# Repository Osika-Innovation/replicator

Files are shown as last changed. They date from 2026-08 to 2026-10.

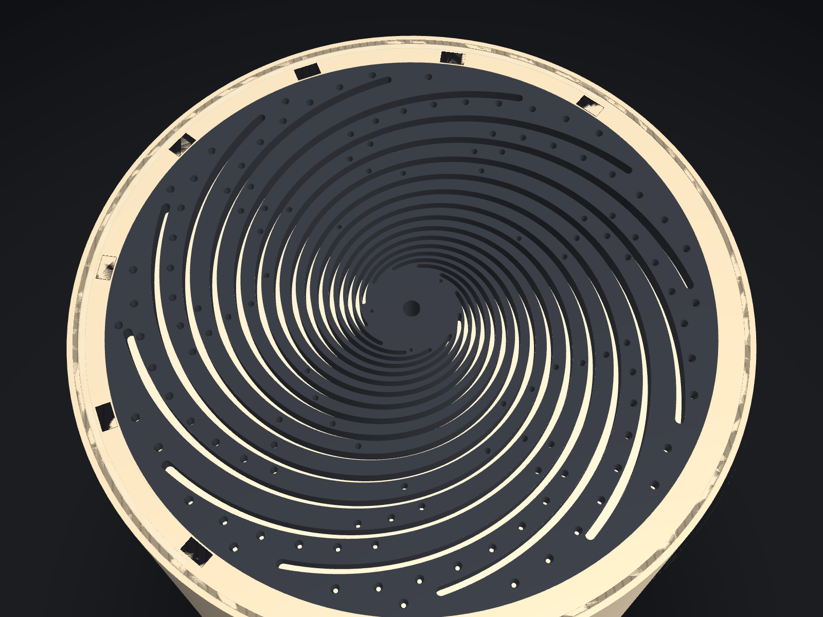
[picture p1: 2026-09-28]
cad/rh1-freestanding/renders/rh1_plate.png

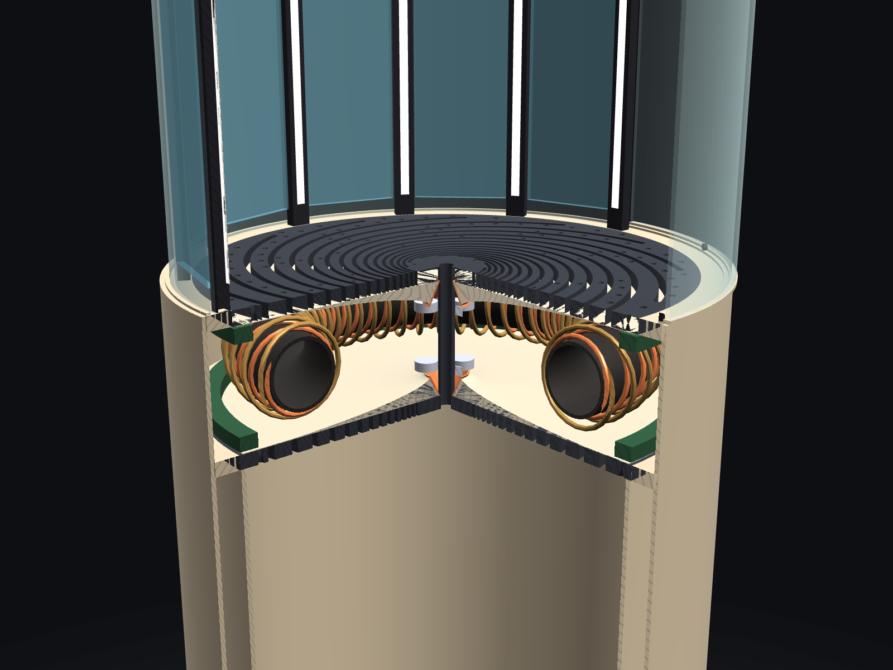
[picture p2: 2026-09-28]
cad/rh1-freestanding/renders/rh1_detail.png

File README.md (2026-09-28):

# The Replicator

**Holographic matter manipulation** — a machine that scans, assembles, and
dissolves objects with shaped acoustic and electromagnetic fields. No nozzle,
no moving parts: the walls of the build chamber command the field, the field
commands the matter.

This is the open engineering repository of
[Osika Innovation](https://osika-innovation.lovable.app). The guided story —
architecture, physics, roadmap — lives on the site; this repo is the working
material behind it: the digital twin, the CAD, and the research papers.

> Two chambers — one holds the object, one holds the matter it will become;
> between them, one plate.

## Layout

| Path | What it is |
|---|---|
| [`twin/`](twin/) | **RSW-1, the field compiler** — the machine's digital twin. Native Swift + Metal: the free-standing RH-1 as a parametric solid model ([`twin/CAD.md`](twin/CAD.md) — 92 parts, CAD gates, section-cut Machine tab, STL/OBJ/STEP export), T0 Rayleigh–Sommerfeld propagator with exact adjoint, T1 acoustic FDTD, T2 Gor'kov radiation forces, inverse solvers (IBP / GS-PAT / Diff-PAT), physics acceptance gates that write receipts, and a headless render/screenshot harness. `swift build` and go — no Xcode required. |
| [`papers/`](papers/) | The research corpus: principles, architecture, the RH-1 hardware specification, the three modes (scan / assemble / dissolve), the two carriers (phonons / photons), stores, memory & compute, bounds analysis, and the field-compiler specification. |
| [`cad/`](cad/) | [`cad/rh1-freestanding/`](cad/rh1-freestanding/) — the RH-1 CAD **generated by the twin**: STEP assembly, general-arrangement drawing, BOM, parameters, renders, and a rev3 Blender render model; plus plate and table-assembly sources (OpenSCAD / CadQuery) and the 12-port bench chamber. `rh1_freestanding_rev2.blend` is kept for history and is superseded (it predates the Ø12 bore). |
| [`sims/`](sims/) | Pre-registered simulation studies. Predictions are frozen before the run and results are published either way — including the negative ones (see the quasicrystal array study in `papers/`). |

## How we work

Every claim in the papers carries a register — **measured** (demonstrated in
published experiments), **derived** (follows from measured physics by
calculation), or **open** (not yet demonstrated, named as such, attached to a
concrete gate). Candidate designs are tested against pre-registered criteria,
and design decisions are recorded with their full history; nothing is
silently rewritten. The twin enforces the same discipline in code: physics
acceptance gates write timestamped receipts, and the emulator's API is the
hardware's API.

## Licensing

- Code (`twin/`, `sims/`) — [Apache License 2.0](LICENSE)
- Hardware design files (`cad/`) — [CERN-OHL-P v2](cad/LICENSE)
- Papers (`papers/`) — © Osika Innovation, all rights reserved for now;
  published openly on the [site](https://osika-innovation.lovable.app/research)

We publish our designs because we would rather live in a world where a
hundred groups extend this machine than one where one company owns it.

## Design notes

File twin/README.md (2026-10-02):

# field-compiler — RSW-1

Native macOS implementation of the Field Compiler.
Spec: [`papers/replicator_field_compiler.html`](../papers/replicator_field_compiler.html) (v0.8).
CAD: [`CAD.md`](CAD.md) — the free-standing RH-1 as a parametric solid model inside the twin.

## Build and run

No Xcode required — Command Line Tools only.

```sh
swift build -c release
./.build/release/fieldc test              # unit suite (62 tests; FIELDC_VERBOSE=1 prints every measured value)
./.build/release/fieldc gate --receipt    # physics acceptance gates, writes Receipts/
./.build/release/fieldc machine           # the simulated machine: RH-1 free-standing, room air (--desktop: frozen v0.3)
./.build/release/fieldc focus             # compile a centre trap on the full chamber (GPU port fields)
./.build/release/fieldc gpu               # Metal propagator + port-field kernel vs CPU reference
./.build/release/fieldc drift --receipt   # how fast a compiled trap goes stale as the air warms
./.build/release/fieldc forcetrap --receipt   # compile for force vs GS-PAT: unique trap? thermal hold? (--glass)
./.build/release/fieldc tonesweep --receipt   # glass chamber: sibling ratio vs number of tones (--target, --liner)
./.build/release/fieldc wallsweep --receipt   # glass liner / plate reflection grid (--plates)
./.build/release/fieldc levitate --receipt    # the drive to hold PLA / aluminium / steel against gravity, in SI
./.build/release/fieldc carry --receipt       # pick up, carry 5 mm up and 5 mm across, place (G-P1)
./.build/release/fieldc fly --receipt         # integrate a PLA bead through the carry: drive level × step time (G-P2)
./.build/release/fieldc build --receipt       # the first build: N beads laid in a row on a support (G-B1; --beads N)
./.build/release/fieldc build --shape tetra --row-dir y --receipt   # four beads: a triangle and one in its pocket (G-B2)
./.build/release/fieldc arraysweep --receipt  # open air: what N elements per plate and the tones buy (study S1)
./.build/release/fieldc mold --receipt        # the sieve in open air, 2 × 192 elements (--shape tetra, --rotate, --sites, --light)
./.build/release/fieldc mold --chamber glass --receipt   # the glass chamber of Rounds 7–11 (--objective wells: the λ/4 limit)
./.build/release/fieldc scan3d --object ring --receipt   # gated pulse-echo scan in open air (point | ring | tetra | R; --chamber glass)
./.build/release/fieldc replicate --receipt   # scan → read the shape → mold a copy → scan the copy (--object tetra)
./.build/release/fieldc render iso a.png  # offscreen machine render, no window server
./.build/release/fieldc shot --all        # every UI scene, both themes + contact sheet
./.build/release/fieldc broadband         # channel-count study: free field vs cavity+chord
./.build/release/fieldc cad check --rules  # the RH-1 solid model: CAD gates + design rules
./.build/release/fieldc cad render --all   # iso, front, section, detail, plate, storage, top
./.build/release/fieldc cad export         # STL per part, OBJ+MTL, params, BOM, GA drawing
./.build/release/fieldc cad step           # B-rep STEP assembly via CadQuery, volume-gated
./.build/release/fieldc plates             # can 6 throat gates hold a trap? (model study)
```

## Status — honest

**2026-09-28 — the machine exists as CAD, and the physics reads it.** The
twin now carries the free-standing RH-1 (Ø460 × 1650, three plate assemblies,
four radiating faces, two chambers, rotating glass, arcade, six photonic bays)
as a parametric solid model built from the newest sources — etherworks.io
(2026-08-10), mech §3c (2026-08-03), spec v0.4 — with every number's
provenance and nine documented conflicts resolved in code (see
[`CAD.md`](CAD.md)). 92 closed solids, 9 CAD gates + 25 design rules, a shaded
section-cut Machine tab, STL/OBJ/STEP exports with a cross-kernel volume gate.
A new preset, `RH1Freestanding`, takes its acoustic apertures from the CAD's
plate faces and its gates from the throat piezos; the desktop preset (`RH1`,
24 panel gates) is FROZEN: it backs the historical solver gates below and
replays old receipts, nothing else.

**2026-09-29 — every mode now simulates the free-standing machine, in real
air.** Compile/Build/Inspect, the viewport chrome, `focus` and `render` run on
`RH1Freestanding.standard()`: 6 throat gates, 17 184 virtual apertures, both
plates as walls, humid air at 20 °C / 50 % RH. See "Round 6" below.

**2026-09-29, later — the glass chamber, exactly, and unique traps inside it.**
The build chamber is modelled as the glass cylinder it is (bare or lined), and
a force compiler that works in its speckle holds one trap with 3–10 tones, on
axis and off. A liner is not the lever; temperature tracking is. See "Round 7".

**2026-09-29, evening — how hard to drive, and a carried bead.** In SI units a
PLA bead needs ~160 dB and steel ~168 dB in the glass chamber (MODEL: the horn
is a stub). The twin carries a trap 5 mm up and 5 mm across on its point,
downhill every step (G-P1). A PLA bead integrated through the fields rides it
at 4× the holding drive, 10 mm in 0.4 s (G-P2). See "Round 8".

**2026-09-30 — the first builds.** Five PLA beads are laid in a row on a
support, each within 2–3.5 µm of its site and touching its neighbour (7–9 µm
gaps). This works by compiling the force balance rather than the potential
minimum, and by placing closed-loop (G-B1). A tetrahedron follows: a fourth
bead rests on three, touching all of them (G-B2). See "Round 9".

**2026-09-30, night — scan an object, mold from powder.** The twin images a
3D object from the six gates (a 30 mm tetrahedron frame at 100 % recall; the
letter R readable). A random cloud of Ø40 µm powder then ends 100 % on a
16-site ring, and 100 % on a 12 mm tetrahedron frame, within 2–4 s. That works
as a sieve: gravity carries the powder, and the compiled field makes the shape
the only place that can hold a grain up. A mold of wells alone catches only
the ~23 % that starts within λ/4 of the shape. Open: an even share per site.
See "Round 11".

**2026-10-01 — the axis bug.** The GPU cavity fields were exactly zero on the
chamber axis, where every mid-plane target sits. Fixed and gated
(G-GPU-CYL-axis); every affected receipt was re-run at 77df809, and the
conclusions of Rounds 7–11 hold with corrected numbers. See "Round 11".

**2026-10-01, later — open air, and the loop closes.** Per
[`ENGINE.md`](ENGINE.md) the glass is gone: two Ø410 mm plates in open air,
each a surface of N independently driven elements. The engine is
matrix-free on the GPU (a mold compile takes minutes of GPU and seconds of
CPU) with basin maps instead of particle stepping. Channels buy power; tones
buy confinement (2 × 192 elements, 9 tones over 30–70 kHz). The scan is
time-gated pulse-echo. The replicator's loop — scan a wire ring, read it,
mold it from powder, scan the copy — closes with every gate passing. Open:
reading small 3D wireframes; evenness that does not depend on orientation.
See "Round 12".

**Implemented and gated:** FieldCore (pure Swift, zero dependencies) —
complex/vector math, RH-1 geometry, mesh + voxelizer, T0 Rayleigh–Sommerfeld
propagator with exact adjoint, T1 acoustic FDTD, T2 Gor'kov radiation force,
the inverse solver (IBP / GS-PAT / Diff-PAT), gate framework and receipts.

**FieldGPU (Metal):** runtime-compiled shaders, GPU propagator validated against
the CPU reference to 3.8e-6, scene geometry for the RH-1 machine, an orbit camera,
and offscreen rendering to CGImage — the viewport half of the screenshot harness,
working with no window server.

**FieldUI (SwiftUI):** the slicer shell — mode tabs, object rail, viewport pane
with overlay chips, inspector, transport bar — as a pure function of `AppState`
(law L1). Dark and light themes. An 8-scene registry and a contact-sheet
generator; `fieldc shot --all` produces 16 PNGs plus two contact sheets headlessly.

**Machine model now carries the two levers a plain-array model lacks:** cavity
walls (axial image sources) and per-tone rainbow gate→element weights.

**Scan pipeline (M7) — wired end to end, physics PARTLY validated.**
`fieldc scan` runs: FDTD pulse-echo with a scatterer → empty-chamber reference →
differential → real S[rx][tx] scattering matrix → matrix pencil → chords →
`.pattern` → Machine View L0 → gates. Working and gated: `.pattern` round trip
bit-exact (G11), reciprocity QC on a genuine scattering matrix (G15, 0.001), and
**L1 DORT correctly REFUSES to image without a measured Green's function** — the
guard that stops a confident, sharp, meaningless picture reaching a `.pattern`.
Chord extraction recovers a pole at **10.68 kHz against a 10.72 kHz drive**,
which says the pencil is finding real physics.

**Not yet built / not yet working:** T0.5 BEM, T1f CBS, T3 consolidation,
`.fcode` I/O, Machine View L2–L3, golden-image *diffing* (screenshots generate
but are not compared against committed goldens), live MTKView interaction.

So: **M0–M2 and M4 done and gated; M1 done for geometry and viewport; M7 wired
with two known defects (below); M3, M5, M6, M8, M9 not.**

## Gate results (Apple M5)

All 10 gates pass. `G9b` reports informational — see below.

| gate | measures | result |
|---|---|---|
| G1 | voxelizer volume vs 4/3πr³ | 0.40% (bar 2%) |
| G2 | energy drift, lossless, 10k steps | 0.71% (bar 1%) |
| G3 | axial round-trip time of flight | 0.44% (bar 2%) |
| G6 | standing-wave node spacing vs λ/2 | 2.5e-5 (bar 1%) |
| G7 | Gor'kov numeric vs closed form | 3.6e-7 (bar 2%) |
| G9a | lateral focus placement, single plate | 1.79 mm (bar 2.64 mm) |
| G9c | best method vs IBP focusing gain | 1.00× (bar > 0.98) |

## Round 12 — open air, physics-limited plates, an engine built on linearity (2026-10-01)

Built to [`ENGINE.md`](ENGINE.md), after the operator's decisions of 1 October:

* keep the cylinder but drop the glass (two Ø410 mm plates, 460 mm apart,
  open air between them);
* make each plate a holographic surface limited by physics, not by "three
  horns per face";
* make the engine efficient before spending compute on it.

### The engine

* **Plates of independently driven elements** (`PlateArray`). Each plate
  carries N Ø5 mm pistons on a Vogel spiral, so every element sits at its
  own radius and there are no grating lobes. Each element has its own drive
  channel. The plates reflect with R = 0.9, imaged to order 3.
* **Matrix-free on the GPU** (`ArrayFieldGPU`, `Shaders/array.metal`).
  * One pass gives p and ∇p at any points for a drive.
  * A second gives, for every element, the gradient of any weighted sum of
    the Gor'kov potential.
  * Nothing is stored, so N can be thousands.

  Gates: G-A1 (potential vs the CPU reference) 3.4e-5; G-A3 (adjoint)
  5.6e-5; G-A2 (one element vs the Rayleigh integral over its face, at
  230 mm and 0–42°) 0.87 %.
* **One compiler for any field** (`ForceCompiler.ForceField`). The mold,
  funnel and sieve compilers run on the glass chamber's stored rows or on
  the plate array.
* **Basin maps instead of trajectories** (`BasinMap`). Overdamped powder
  slides down U_eff = P·U + mgz and stops in a minimum. So every lattice cell
  points to its steepest descent, and following the pointers gives the end
  of every start at once. Recirculation closes in one line. G-B0: the basin
  map and 3,000 stepped grains agree on the share that ends on the shape.
* **Basin-map feedback.** Sites that get less than their fair share are
  weighted up and the drive is recompiled from the last one. This is what
  the machine would do with a scan.
* **Cost.** A mold compile at the design point takes 2–3 minutes of GPU
  time with a few seconds of CPU; a scan takes ~45 s; peak memory is
  ~50 MB.
  * Per-call GPU buffers were first kept alive by their command buffers and
    grew 0.4 GB/s. That killed the first sweep silently. Buffers are now
    allocated once per field.

### What the channel count and the tones buy (`fieldc arraysweep`, study S1; receipt at 9e5b63d)

Centre-trap ratio (< 0.5 = unique), and the 16-site ring sieve by the basin map:

| per plate | tones (30–70 kHz) | trap ratio | powder on the ring | sites (fair 6.25 %) | drive per element | acoustic power |
|---|---|---|---|---|---|---|
| 3 | 1 | 0.78 | 4 % | — | 476 m/s | 5,512 W |
| 12 | 3 | 0.18 | 97 % | 0–25 % | 51 m/s | 745 W |
| 48 | 9 | 0.10 | 100 % | 0–16.5 % | 10 m/s | 349 W |
| 192 | 1 | 0.67 | 15 % | — | 9.2 m/s | 131 W |
| 192 | 9 | 0.11 | 100 % | 3.3–8.6 % | 2.2 m/s | 67 W |
| 768 | 9 | 0.08 | 100 % | 4.0–9.3 % | 0.62 m/s | 21 W |

What the channel count and the tones buy

* **Tones buy confinement along the axis.** Two plates make standing waves
  every λ/2 all the way between them, so lift exists at every node plane.
  Only frequency diversity localises it. One tone never makes a unique trap
  (~0.7 at any N). Nine tones over 30–70 kHz make the centre trap unique
  (~0.1), and the sieve puts all the powder on the ring. This is Round 7's
  "tones are drives", now separated from the channel count.
* **Channels buy power and evenness.** Going from 3 to 768 elements per
  plate cuts the acoustic power ~100–170×. Every site getting its share needs
  192 or more.
* **Design point:** 2 × 192 elements, 9 tones over 30–70 kHz. That is
  ~2.2 m/s rms per element and ~67 W acoustic to hold the whole powder
  cloud. At 2 × 768 it drops to 0.6 m/s and 21 W.

### Molds in open air (receipts at 9af9c1f)

At the design point (2 × 192 elements, 9 tones), with the basin map and
3,000 stepped grains:

* **The 16-site ring:** 100 % of the powder ends on the ring. All 16 sites
  hold powder (3.3–8.6 % each against a fair 6.25 %; grains 21–348 each).
  Nothing is left in a rogue well; 1.2 re-sprinkles per grain (G-M1, G-M2,
  G-B0 pass).

  Open air: the ring
* **The 12 mm tetrahedron frame, in 3D:** 98.5 % on the frame by the basin
  map, 100 % by the grains. All 10 sites hold powder (7.7–13.1 % against a
  fair 10 %) (G-M1, G-M2, G-B0 pass).

  Open air: the tetrahedron frame
* **Evenness depends on orientation (found by turning the shape).**
  * Capture onto the shape is robust: 100 % at every rotation tried.
  * Even filling is not. The 16-site ring (sites 3.1 mm apart) leaves sites
    empty when turned 5° or 11.25°.
  * With 12 sites (4.2 mm apart) every site fills at 0° and 5° (7.4–9.1 %,
    6.4–10.3 %) but one stays empty at 11.25°.

  The plates' Vogel spirals are not rotationally symmetric, and 3.1 mm is
  only ~1.3 half-wavelengths at 70 kHz. Feedback rounds (weight starved
  sites up, recompile) have not recovered a site the powder never reaches.

### Scans in open air: pulse-echo, time-gated

A first version lit the object with random chords on both plates and listened
on both. That is mostly transmission (plate → object → other plate), whose
path barely changes with height, so the image smeared ~10 mm along z. The
reflecting plates add plate → object → far plate → home paths of 2L whatever
the height. The scan is now pulse-echo, one plate at a time:

* coded pulses (one random phase pattern per plate, the same at every
  frequency);
* 320 frequencies over 30–100 kHz (a 4.6 ms window);
* a time gate on the direct echoes (1.2–1.9 ms; the first plate bounce
  arrives at 2.7 ms).

A point's half-peak volume fell from 3,726 voxels to 320.

| object | bright voxels on the object | object recalled | peak offset | time |
|---|---|---|---|---|
| a point | 77 % | 100 % | 1.0 mm | 35 s |
| a wire ring, 8 mm radius | 92 % | 100 % | 0.3 mm | 35 s |
| a 30 mm tetrahedron frame | 67 % | 56 % | 1.0 mm | 31 s |
| the letter R, 40 mm | 73 % | 54 % | 1.5 mm | 31 s |

Open air: a wire ring

The glass chamber's scan took ~5 minutes; these take ~30 s and are cleaner
(higher precision). They recall less of the big objects above half the peak,
because faces turned to the plates echo much more strongly than edges.

### The replicator loop (`fieldc replicate`)

Scan an object, read its shape off the image, mold a copy from powder with
the sieve, scan the copy, and compare. Reading the shape:

* peaks at least 3 mm apart above half the image's maximum;
* each peak moved to the brightness-weighted centroid of its patch
  (sub-voxel);
* sites resampled at equal arc length along every chain and loop, ~4 mm
  apart.

**A wire ring (8 mm radius): the loop closes.** All six gates pass:

* G-R1: 12 sites read, all on the ring (worst 0.39 mm).
* G-M1, G-M2: 100 % of the powder ends on the read shape, every site filled.
* G-R2: the copy lies on the ORIGINAL ring: 100 % of the cloud within
  1.5 mm of it, median 0.45 mm.
* G-R3: the copy's scan correlates 0.72 with the original's (bar 0.7).
* G-B0: the basin map and the stepped grains agree.

The replicator's loop on a wire ring

**A 12 mm tetrahedron frame: the reading step fails.** At the scan's ~2 mm
resolution a frame this small images as a blurred cage. Joining nearby peaks
built a 39-segment mesh instead of six edges: 88 % of its sites lie on the
frame (worst 4.0 mm), and it covers 69 % of it. The mold on that mesh puts
76 % of the cloud on it, but only 59 % within 1.5 mm of the original frame
(G-R1, G-R2, G-R3 fail). Reading a graph off an image needs a skeleton (or a
model fit), not proximity. That is the next step.

The loop on a tetrahedron frame

### Reading with light

Sound changes the air's refractive index, so a laser across the chamber
picks up a phase k_L (n₀ − 1)/(γ P₀) ∫ p dx. Strobed at each tone, a camera
behind a schlieren or interferometer reads the field's line integral
(`fieldc mold --light`). Through the compiled ring mold, a 633 nm beam picks
up up to 0.95 rad (rms over tones). That is easily measured, so light can
calibrate the twin against the real plates and render the field on screen.

What light reads

**Open / next:**

* The eigen-solve compile (seconds instead of minutes).
* Even filling that does not depend on orientation (more channels, more
  tones, or an objective on the catchments themselves).
* Streaming (the flows around foci).
* Grain–grain cohesion and the clump's own scattering.
* The plate element's real transfer, measured on the bench and then read
  with light.

## Round 11 — scan an object, then mold from powder (2026-09-30)

The replicator's own loop is to scan an object and then mold a copy in one
shot. Pick-and-place was the proving ground; this round does the two halves
of the loop.

**Scan (`fieldc scan3d`).** By reciprocity, a small scatterer at x couples gate
j to gate i through what each gate's field does there:

    ΔT_ij(f) ∝ −(f1/3) k²a³ p_i(x) p_j(x) − (f2/2) a³ ∇p_i(x)·∇p_j(x)

The chamber-only transfer is calibrated away. An object is a cloud of such
scatterers (Born approximation; the coupled solve for a few beads). The image
is the matched field over 90 frequencies from 30 to 100 kHz, every gate pair,
40 dB SNR, using the same exact glass-chamber fields:

    I(x) = |Σ_f Σ_ij M_ij(x,f)* ΔT_ij(f)| / (Σ|M|²)^½

| object | recall (object within 2 mm of a bright voxel) | bright voxels on the object | what it shows |
|---|---|---|---|
| 30 mm tetrahedron frame | 100 % | 14 % | the outline in x–y, blurred 2–3 mm; streaked in z by the plate mirrors |
| letter R, 40 mm | 99 % | 33 % | the letter, readable in x–z |
| the twin's own 4-bead tetrahedron | — | — | one blob: 0.36 mm across, below the resolution |

The twin scans a tetrahedron frame
The twin scans the letter R

**Mold (`fieldc mold`).** A cloud of Ø40 µm PLA powder, 3000 grains, is
released at random through a ±10 mm volume. It moves in one compiled
multi-tone field, with gravity on. A grain relaxes in 6 ms in air, so it is
overdamped: it follows the field and does not swing, which is what defeated
single-bead carrying. Force and weight both go as a³, so small grains are not
weightless.

* **A mold of wells catches only what starts near the shape.** The force
  compiler, generalised to many wells (`--objective wells`), forms 13 of the
  16 wells of an 8 mm ring. It puts only 23 % of the cloud on the ring, and
  fills 5 of 16 sites (G-M1 and G-M2 fail). By starting distance from the ring:

  | start (mm from the ring) | 0–1 | 1–2 | 2–3 | 3–4 | 4–5 | 5–6 | 6–8 | > 8 |
  |---|---|---|---|---|---|---|---|---|
  | captured | 88 % | 93 % | 76 % | 37 % | 19 % | 6 % | 2 % | 0 % |

  A still field reaches a grain only within about λ/4 of its lowest tone
  (2.9 mm at 30 kHz). The rest settles in layers a wavelength above and below
  the ring. Gravity is not the limiter: runs without gravity, and at 16× the
  drive, give the same result.
* **No drive makes the whole volume slope toward the shape.** Asking for U to
  fall toward the nearest site at every point (`--objective funnel`) moves the
  funnelled share from 50 % to 52 %, which is chance. A resonant chamber's
  landscape repeats every half wavelength. The funnel objective is kept as the
  negative test.

  A mold of wells alone
* **Gravity is the conveyor; the mold is a sieve.** A grain can come to rest
  only where the lift −∂U/∂z equals its weight. So the compiler instead makes
  the shape the only place that can hold a grain up (`compileSieve`). It
  maximises the weakest site's lift over the most that any point 1.5 mm or
  more from the shape can lift. In the power window between the two, the sites
  hold and every other grain falls. Powder that falls out is sprinkled in
  again at the top, as a hopper or a recirculating loop would. Three more
  terms make the powder spread evenly along the shape:
  * each site is a trap sideways, at its level and one step up, where a held
    grain rests;
  * the band where grains land funnels to the nearest site;
  * that funnel is weighted to the worst-served site. Averaged over all sites,
    the same 2 of 16 stayed empty run after run.

  **Result (40 tones, lift contrast 1.71, drive 1.31× the weakest site's
  hold; receipts at 77df809):** 99 % of the cloud is on the ring within 2 s
  and 100 % by 4 s. Nothing is left in a rogue well and nothing is lost; each
  grain was sprinkled in again 1.0 times on average (G-M2 passes). 15 of the 16
  sites hold powder (49–445 grains); the site at 247° stays empty and its
  neighbour takes a double share (G-M1 fails). Before the axis fix the same
  compile filled all 16 (86–321 grains).
* **The tetrahedron frame (12 mm edges, 10 sites) works too:** lift contrast
  1.94, 100 % of the cloud on the frame within 4 s, all 10 sites holding
  powder, but unevenly, 58–525 grains (G-M2 passes, G-M1 fails at 0.19 of a
  fair share against 0.25).

  The acoustic sieve on a tetrahedron frame

  The acoustic sieve

**What this asks of the machine.** Powder is dispensed from above, and what
falls through is collected and dispensed again. The drive sits inside a window
set by the lift contrast. At contrast 1.71 the drive power must stay within
−24 % … +31 % of the window's middle, so the drive level must be known that
well: calibrated through the scan, and tracked as the air warms (Round 6). The sites are 3.1 mm apart,
about λ/2 at the top of the band. A continuous part needs the clumps to merge
or be bridged (binder, sintering), which is not modelled.

**The axis bug (found 1 Oct, fixed at 77df809).** The first sieve compile of
the tetrahedron froze: its apex site, on the chamber axis, showed exactly zero
lift. Probe lattices are centred on their target with an odd point count, so a
target on the axis puts a lattice column exactly on x = y = 0. There the Metal
cavity kernel returned exact zeros for every tone and every component (φ =
atan2(0, 0) under fast math). The CPU reference was right for p but took the
m = ±1 gradient term J_m(μr)/r from a spline extrapolated below the table's
first step. Both now use the series below the first step and φ = 0 on the
axis. A new gate, G-GPU-CYL-axis, compares GPU and CPU exactly on the axis and
1 µm off it: 0.59 before, 6.3e-6 after. Every glass-chamber receipt with
on-axis content was re-run at 77df809 (Rounds 7, 8, 10 and 11 above). The
plates-only runs and the off-axis targets do not use this kernel. The
conclusions hold; the numbers moved by up to ~30 % (the 1-tone mid-plane ratio
0.88 → 1.19; the 5-tone chord 0.42 → 0.34). The sieve compile also no longer
lets a zero lift set a zero temperature. And G-M1 now needs every site to hold
at least a quarter of its fair share: a bare "every site has a grain" passed
the frozen run.

**Open:** an even share per site (G-M1). Not modelled: grain–grain contact and
cohesion, the clump's own scattering (`Scatterers` exists for it), and
streaming.

## Round 10 — part growth: the part is in the field (2026-09-30)

**Placed beads scatter** (`Scatterers`). Each bead scatters as a monopole
(compressibility contrast f1) plus a dipole (density contrast f2). It is driven
by its local field: the chamber's plus every other bead's scattered field, so a
cluster's multiple scattering is solved per gate (coupled dipoles). Everything
stays linear in the drive, so the part adds per-gate rows that the compiler,
the carry and the force balance all see. The gates:

* **G-S1:** the exact rigid-sphere series at ka = 0.1, matched to 1.3 %.
* **G-S2:** the time-averaged interaction energy of two beads in an
  oscillating flow, −(π/2) f2² ρ0 a⁶ v² (1 − 3cos²θ)/R³ (Koenig), matched to
  1.0 %. Beads attract side by side and repel end to end.

**What the part does to a build.** The part changes how every later bead
has to be placed:

* **A balance next to a neighbour is a saddle.** The neighbour's pull near
  contact is comparable to the trap's force. Beads therefore land 0.6 mm back,
  outside the ~5-radius capture range, and are slid in along the support. The
  slide trap is aimed on the chamber field alone, so trap and attraction pull
  the same way into contact.
* **Rows are laid across the local flow.** The first scattering build grew
  along y by itself: along the flow, neighbours repel.
* **Stacking is dropped, not pushed.** Above its neighbours a bead is end to
  end along the mostly vertical flow, where they repel. The repulsion scales
  with the drive, so more power does not help; gravity does not scale, so the
  top bead is centred 0.5 mm up and dropped.
* **Contact is physical.** The support pushes back and resists rolling. A bead
  that touches a placed bead is held by the binder as a liquid bridge. The
  machine then releases it, it settles under gravity along its contacts, and
  the bond cures.

The row passes (G-B1): all five beads on the support, gripped to their
neighbours, 10–13 µm from their sites (re-run at 77df809). The tetrahedron passes with its base
along y (G-B2): the base closes by attraction, and the top bead settles into
the pocket at 163.3 µm, which is 2a·√(2/3), touching all three.

**Open:** with the orientation chosen automatically, the tetrahedron's carries
still lose a bead. Traps are soft and can be saddles off-axis, so a carry path
must be checked for trappability before it is committed. Placed beads now take
up to 16× their weight from the traps that bring the next bead.

**Where this goes next.** Pick-and-place was the proving ground for the
compiler, the part's field and the bead dynamics. The replicator's own loop is
to scan an object, then mold a copy in one shot: one field whose wells form the
whole shape, filled with powder that is overdamped and follows the field
without swinging. That is the next round.

## Round 9 — the first build (2026-09-30)

**Five beads laid in a row (`fieldc build`, G-B1).** Five Ø200 µm PLA beads are
laid in a row on a support in the glass chamber. Each is loaded into the
unique 10-tone trap at the mid-plane and carried across and 2 mm down. It is
then lowered onto the support beside the previous bead, and fuses where it
first touches (a binder coat).

The twin's first build

* **Compile the force balance, not the potential minimum.** A bead under
  gravity rests where the trap's force equals its weight, not at the
  potential's minimum. Compiled as a minimum, a loaded bead hung 0.2 mm low and
  0.5 mm aside, because the well is soft sideways and its axes tilt. That
  scattered the first attempt's beads by 0.3–2 mm, one perched on another.
  `moveWell` and `carryStep` now take the external force per unit drive power
  (∇U(x) = −(mg/P) ẑ), so the bead rests on its aim.
* **Solve the balance where the bead lives.** On the 0.63 mm probe lattice the
  interpolated balance point sat 1.2 mm from the fine field's. The balance is
  now re-solved on a 0.1 mm box of exact modal rows; the lattice still does the
  rival suppression.
* **Closed-loop placement.** Before and during the lowering, the twin reads
  where the bead hangs (as the machine's scan would) and moves the well by the
  bead's miss. Each next site is laid off the placed bead's actual position.
* **Result:** 5/5 beads on the support, 2–3.5 µm from their sites, neighbours
  7–9 µm apart. The aim was 10 µm, so a miss leaves a gap rather than a perch.
  The row is straight to ±2 µm, and the build takes 8.5 s of simulated time.
* **A requirement it found:** the traps that bring later beads push the placed
  ones with up to 4.5× their weight. The binder, or the fuse step, must hold
  that.

**A tetrahedron (`fieldc build --shape tetra`, G-B2): a bead laid on beads.**
Three beads are laid touching on the support, each off the others' actual
positions; the third goes at the apex of the triangle on the first two. A
fourth is lowered into their pocket. It first touched bead 1 and rests against
all three: gaps 1.7, 0.0 and 3.3 µm, 11 µm from the pocket. The base gaps are
5–9 µm, and the build takes 6.7 s of simulated time.

The twin's second build: a tetrahedron

`python3 Tools/plot_build.py` redraws the row from `Receipts/build_*.csv`;
pass the `build_tetra_*` files, an output path and a title for the tetrahedron.

**Not modelled:** scattering by the support and the placed beads (the support
is taken as an acoustically open mesh); secondary Bjerknes forces between
beads; streaming; how the binder cures.

## Round 8 — how hard to drive, and how to carry (2026-09-29)

**Placement is pinned.** A force-compiled well now sits within λ/8 (≈ 1 mm) of
the requested point, positions sub-grid (a parabola per axis). The price in the
glass chamber at 10 tones: sibling ratio 0.24 → 0.36, still unique.

**`fieldc levitate` — the drive to hold a bead, in SI.** The rows are pressure
per unit aperture velocity (Pa per m/s), so a compiled drive is a set of
aperture velocities at horn coupling 1. The horn is still a stub, so these are
MODEL numbers until bench G-A0 measures the throat → aperture gain. The study
reads the largest upward force the trap's well offers along a 20 µm vertical
line, and scales the drive until that force carries the bead's weight. Force
and weight both scale as a³, so in the Rayleigh limit the answer depends on the
material, not the size. Hardest-driven gate, velocity amplitude (receipt):

| trap | PLA | aluminium | steel | field peak, PLA / steel |
|---|---|---|---|---|
| plates only, 5 tones | 26.3 m/s | 38.8 m/s | 66.2 m/s | 160 / 168 dB |
| glass chamber, 5 tones | 9.0 m/s | 13.2 m/s | 22.5 m/s | 162 / 170 dB |
| glass chamber, 10 tones | 4.5 m/s | 6.6 m/s | 11.2 m/s | 159 / 167 dB |

* The glass keeps the energy in: the same trap needs 2.5–6× less drive than the
  plates alone.
* PLA needs a ~160 dB field — the level working acoustic levitators use. Steel
  needs ~168–171 dB, where the air turns nonlinear (shock distance ~6 cm at
  160 dB) and streaming drag on fine powder rivals its weight. That is where
  the next physics layers — nonlinearity and streaming — stop being optional.
* Lateral stiffness is weak: 3–24 Hz for PLA at the holding drive.
* Re-run at 77df809 (the axis fix; the targets sit on the axis): the glass rows
  moved by up to 12 % (5 tones) and < 1 % (10 tones). The plates-only row moved
  ~3 % with the compiler's normalised gradients.

**`fieldc carry` — pick up, carry, place (G-P1).** Re-compiling at each step of a
path either kept the old well while the target moved away (three steps) or
hopped 4.5 mm to another. Placing the well by Newton alone kept it on the point
while the rivals grew until the trap was lost (0.43 → 0.97 in four steps). The
carry step does both at once:

* a Newton step on ∇U(x) = 0 — the smallest drive change that puts the well on
  the point (`ForceCompiler.moveWell`);
* a rival-suppression step projected onto that constraint's null space, so it
  does not move the well (`ForceCompiler.carryStep`).

In the bare glass chamber with 10 tones, the trap was carried 5 mm up and 5 mm
across in 40 steps of 0.25 mm. Every step was within 0.17 mm of its point,
continuous, and downhill from the old well. The bead's well stayed the deepest
throughout, never below 0.71 of its starting depth. 36 of 40 steps were also
globally unique (worst 0.72, the first). Global uniqueness is the loading
criterion; a bead already in its well needs its own well and a clear path.

**`fieldc fly` — a bead that moves (G-P2).** A 200 µm PLA bead is integrated
through the carried trap: time-averaged Gor'kov force from a 0.1 mm box of
exact modal rows around the path, gravity, Stokes drag (streaming ignored).
Each drive change is ramped linearly, then settles with the chamber's τ
(air absorption + plate loss, 3.5 ms at 50 kHz).

* **Dropped in and stepped hard, the bead is lost.** Air damps a 200 µm bead
  in ~150 ms and the trap is ~8 Hz sideways, so it never settles. Whether a
  step keeps it depends on the swing's phase: lost at 10 and 40 ms per step,
  carried at 20 and 80. The static carry (G-P1) is not enough for a real bead.
* **Loaded gently, with ramped steps, it rides.**
  * At 2× the holding drive: carried at every step time from 10 to 80 ms per
    0.25 mm step, ending 0.29–0.33 mm off the drop-off.
  * At 4×: carried at every step time down to 10 ms. The whole 10 mm path
    takes 0.4 s, and the bead ends 0.13–0.15 mm off the drop-off, which is its
    sag.
  * At 8×: carried, ending 0.07–0.08 mm off.
  * (Re-run at 77df809, after the axis fix: before it, the 2× bead escaped at
    10 ms and the 4× bead sagged 0.21 mm.)

A PLA bead carried 5 mm up and 5 mm across

`python3 Tools/plot_fly.py` redraws it from `Receipts/fly_trajectory_4x_40ms.csv`.
The bead trails the stepped target by 0.2–0.5 mm going up (sag plus lag) and
wobbles ~0.2 mm sideways at the trap's 8 Hz. **Fine powder is a different
regime:** drag goes as a/a³, so a 30 µm grain is overdamped (1/e in ~3 ms)
and would follow the trap without swinging, but there streaming and
cohesion take over.

**Not modelled yet:** cross terms during a ramp (the potential is blended,
not the drive); acoustic streaming; several beads at once; the horn.

## Round 7 — the glass chamber (2026-09-29)

**The build chamber is a glass cylinder, and the twin now has it.**
`CylinderCavity` solves the chamber as an exact modal sum: the rear glass
(Ø444 OD, 4 mm wall → a = 218 mm) between the two plates, 460 mm apart.

    p = Σ_mn J_m(γr) e^{imφ} [W0 Z0(z) + WL ZL(z)]

Along z the plate images are summed in closed form; across the chamber every
glass reflection is exact (4 mm glass is a mirror: 69–83 dB transmission loss
at 40–200 kHz). At 40 kHz ~9 000 mode coefficients per gate stand in for
17 184 apertures × 7 image paths — the chamber's screen, made literal. One
Miller table serves every Bessel order; `CavityFieldsGPU` runs the sum on Metal.

**A lined glass wall, exactly.** A liner of specific admittance β sets
∂p/∂r = ikβp on the wall. Each mode's zero is continued from its rigid j′ₘₙ to
the root of x J′ₘ(x) = i(kaβ) Jₘ(x), and Jₘ at the complex argument is read off
the same real table by the multiplication theorem (DLMF 10.23.1), on the CPU
and in the kernel. Low modes graze the wall and turn pressure-release-like
with little loss; modes that meet it head-on are the ones a liner kills. (The
first-order perturbation this replaced fails once kaβ ≳ j′ — β ≈ 0.05 at
40 kHz already.)

| gate | checks | result |
|---|---|---|
| G-CYL1 | far wall absorbing → the half-space Rayleigh field | < 5e-3 |
| G-CYL2 | closed rigid cylinder rings at its analytic (0,0,1), (1,1,0) frequencies | pass |
| G-CYL3 | plate-mounted sources: 16-order image series = the cavity's plate series | 1.1e-5 |
| G-CYL4 | lined-wall zeros vs 30-digit mpmath continuations | 2e-9 |
| G-CYL5 | lossless air, lined wall: power in = power into the liner | 1.1e-6 |
| G-CYL6 | lined field: Helmholtz / wall condition / gradient vs finite differences | 1.1e-4 / 2e-10 / 1e-5 |
| G-GPU-CYL, -lined | Metal vs CPU, p and ∇p, bare and lined | 8.3e-6 / 8.5e-6 |

**A bug the cavity caught.** The image model placed a plate-mounted aperture
between the walls and then added that plate's own image at the source point —
but the Rayleigh prefactor already baffles it, so every image came twice and
the field was (1 + R) = 1.9× too strong. Up to the last truncated image that is
a uniform scale, so ratios barely moved, but absolute pressure was 1.9× high,
which matters the moment drives are in SI units. Fixed on the CPU (2fbccfb);
`fieldc gpu` then caught the Metal kernels still doing it (G-GPU-FS read 0.90),
fixed in 50eb595.

**A force compiler that works in speckle.** In the glass chamber the heuristic
refinement (penalise the 24 deepest siblings) returned its GS-PAT start
unchanged: hundreds of speckle wells, and with five tones it scored worse than
one tone can — which no optimum can. `ForceCompiler.smooth` minimises the
softmax of every rival well's depth over the target well's with Adam on the
unit sphere of drives, from an exact adjoint (checked against finite
differences, 1.5e-9); a chord starts from each tone compiled alone (equal,
quality-weighted, and the best tone alone). Everything below uses it.

**What the glass does to a trap, and what brings it back** (`fieldc forcetrap
[--glass]`, `fieldc tonesweep`, `fieldc wallsweep`; receipts at 00bcc24; every
glass row with its target on the axis re-run at 77df809, after the axis fix —
see "The axis bug" below).
Sibling ratio, force compiler (< 0.5 = one trap; siblings above half depth in
brackets):

| chamber, target | 1 tone | 3 tones | 5 tones | 10 tones | 20 tones |
|---|---|---|---|---|---|
| plates only, mid-plane | 0.91 | | **0.25** (0), G-F1 | | |
| plates only, 100 mm above the lower face | 0.90 | | **0.31** (0) | | |
| bare glass, mid-plane (30–70 kHz grid) | 1.19 | | **0.34** (0) | | |
| bare glass, mid-plane (tonesweep spacing) | 1.01 | **0.41** (0) | 0.66 | **0.33** (0) | **0.14** (0) |
| bare glass, 60 mm off-axis | | | **0.49** (0) | **0.22** (0) | **0.18** (0) |
| bare glass, 100 mm above the lower face | | | **0.33** (0) | | |
| GS-PAT chords only, mid-plane | 6.91 | 1.22 | 4.35 | 0.65 | 0.83 → 0.45 at 80 tones |

* **Glass turns the field into speckle**, and a pressure-objective chord needs
  ~80 tones to find its way back to one trap. **Force-compiled, 3–10 tones
  suffice**, on axis and off it — the time–bandwidth argument (I1 below) holds
  in the exact chamber. Tones are drives.
* **A liner is not the lever.** With the force compiler the 5-tone chord reads
  0.34 with bare glass, 0.39 / 0.38 / 0.43 / 0.57 behind liners of normal-
  incidence R = 0.9 / 0.7 / 0.5 / 0.3, and 0.34 behind a ρc-matched one
  (re-run at 77df809; before the axis fix 0.42, 0.42–0.64 and 0.36). A
  locally reacting wall reflects grazing waves whatever its β —
  R(θ) = (cos θ − β)/(cos θ + β) → −1 — and a partial liner's reflection phase
  turns with angle, which scrambles the field further. (An absorber that
  works at grazing incidence — thick, bulk-reacting — is not modelled.)
* **Temperature decides how often to re-compile.** In the glass chamber a held
  5-tone drive stops being unique by +0.1 K (0.60) and loses the trap by +0.3 K
  (1.13); re-compiled at the true temperature it is unique again — 0.44, 0.48,
  0.29 at +0.1 / 0.3 / 1 K — and through +0.3 K it has not moved. So the twin
  must track the air to ~0.1 K and recompile, which is what the fast compiler is
  for. (`fieldc drift`, GS-PAT traps: the glass decorrelates a held trap within
  +0.1 K; a ρc liner makes the drift smooth — 137 / 368 / 496 / 705 µm at
  +0.1 / 0.3 / 1 / 3 K — but does not stop it.)
* **Placement is loose.** A force-compiled well may sit up to λ/4 from the
  requested point (1.9 mm on the plate-only chord); building needs it on the
  point. Next: pin the target in the objective.

## Round 6 — temperature, port fields, and the free-standing machine (2026-09-29)

Prompted by two external reviews of the chamber-engine plan (Kin note "The
twin's chamber engine: two reviews checked…").

**Air is a model input now.** `Medium.air(temperatureC:humidity:pressure:)` gives
sound speed and density from an ideal-gas mixture of dry air and water vapour,
and absorption from ISO 9613-1: 343.87 m/s at 20 °C / 50 % RH, **+0.182 %/K**;
4.66 dB/km at 1 kHz (the ISO table value), 1.32 / 3.28 / 8.23 dB/m at 40 / 100
/ 200 kHz. Absorption acts on every path, images included; the horn channels
hold the same air (c/√τ), so they drift too. The fixed §12 media are unchanged,
so every earlier receipt still replays.

**Port fields on the GPU.** `PortFieldsGPU` builds the gate-granular operator for
any preset — horn couplings, wall images, absorption — and hands the CPU
pipeline a `Propagator(precomputedH:)`. The whole chamber at λ/2 (792 100 points
× 6 gates, 17 184 apertures × 7 wall paths ≈ 10¹¹ terms) builds in **3.3 s**;
after that every drive is a six-column sum. **G-GPU-FS** holds it to the CPU
reference: 1.3e-5 at 40 kHz, 5.3e-5 at 100 kHz (bar 1e-4).

**How fast a compiled trap goes stale** (`fieldc drift`, receipt): compile a twin
trap at 20 °C, hold the drive, warm the air.
* Direct paths only, the node moves by d·Δc/c (d = distance from the mid-plane):
  **G-T1** passes, +340 µm vs +329 µm closed form and −775 vs −712 µm at +3 K.
* With both plates as mirrors (3 image orders, R = 0.9), multipath turns the
  drift into decorrelation: at 40 kHz the trap moves 40–900 µm within +0.3 K,
  and at 100–200 kHz 0.1 K is enough for a sibling well to take over.
* Re-solving the drive at the TRUE temperature pulls on-axis traps back 2–4×
  with direct paths, but in the reverberant case it lands in a different well:
  the pressure-objective twin trap is not unique with 6 drives. So modelling
  temperature is necessary, not sufficient — the force compiler (Gor'kov
  potential as a quadratic form in the gate vector, sibling wells penalised)
  comes before thermal correction can work.

The live Compile shows the same thing honestly: all 4 000 wells lie within 45 %
of the deepest, median miss 10 mm.

**The force compiler** (`ForceCompiler`, `fieldc forcetrap`). Per tone the Gor'kov
potential is an exact quadratic form in the gate drive, U(x) = gᴴK(x)g, built
from the port-field rows and their analytic gradients (a GPU kernel,
**G-GPU-FS-grad** 1.4e-5). The gradients now include the piston directivity's
angular slope — the old "locally constant" shortcut missed 1–2 % of the lateral
gradient at ka ≈ 1.8 — so rows match finite differences to 1e-8. A well's depth
(shell mean − centre) is then a quadratic form too; the compiler maximises the
target's depth and penalises every competing well deeper than half of it, from
several starts (eigenvector, GS-PAT), warm-starting when the room changes.
* One tone, 6 drives: no unique trap anywhere (sibling ratio 0.94, 8–32 wells
  above half depth). Contrast is capped near the number of drives.
* **Five-tone chord (30 drives) at the mid-plane: G-F1 passes — sibling ratio
  0.43, no competing well within ±17 mm above half the target's depth, 0.6 mm
  from the requested point.** The first unique trap the twin has produced on the
  plate machine; the GS-PAT chord makes no well at the target at all. Warming
  with the drive held, it does not move (0 µm through +1 K); it stays unique to
  +0.3 K (0.49) and loosens by +1 K (0.66).
* 100 mm above the lower face the chord reaches 0.80 — the same as GS-PAT: the
  plate's own standing wave keeps 22 siblings there.

**Still missing** for these numbers to be the machine's: the glass cylinder
(the walls are the two plates only — added in Round 7), the horn (a labelled
stub), and SI drive units.

## Round 5 — what building the machine found (2026-09-28)

Building the geometry surfaced design facts no paper had written down, and
two physics bugs that had been shaping documented results.

**Design findings** (details and reconciliation table in [`CAD.md`](CAD.md)):
only **128 of the 380** sunflower sites can be drilled — 252 fall inside a
spiral slot or its web; per face the slots are **34,600 mm² open against
~2,700 mm²** of micro-horn faces (12.8×), so if the slots are open voids they
*are* the acoustic aperture — **operator ruling needed: open or
dielectric-filled?**; the "21 × 34" parastichies are the mid-field reading
(13 × 21 inside, 34 × 55 at the rim); three Ø25 throat piezos on r = 18 reach
0.5 mm into the Ø12 bore (model uses Ø20); the spec's storage chamber and its
own middle stack overlap (the site's layout is the one that closes); the
model weighs ≈69 kg against the spec's "≈50 kg class".

**Bugs, continuing the numbering:**

15. **Wall image series wrong beyond first order.** Every extra order re-added
    the two first-order images (so they carried R + R² + R³ = 2.44 instead of
    0.9) and put fourth-order images where third-order ones belong. The series
    is now derived per bounce count and pinned by a test against an explicit
    alternating-reflection recursion.
16. **The inverse solver optimized a different machine.** Its control matrix
    re-walked the elements in free field with no wall images, no element
    weights and no couplings — so every "walls" and "rainbow" condition solved
    its drive for a machine it was not then evaluated on. With the image
    series corrected, the walls + rainbow condition turned **NaN**, which is
    how it was found. The control matrix now comes from `Propagator.gateRow`,
    the same path as the cached operator.
17. **Point evaluators ignored walls, weights and couplings** — `pressure(at:)`
    and `velocity(at:)` could silently disagree with `forward`. One code path
    now; a test checks agreement with walls and complex couplings on.
18. **The drilled-hole set depended on display tessellation** (200 vs 400
    slot samples changed which sites a slot swallowed). Design facts are now
    decided at a fixed fine resolution; the unit suite caught it.
19. **An 8-sided winding carried 90 % of the round wire's copper**, which the
    STEP cross-check would have reported as a kernel disagreement. Wire
    polygons now use an area-equivalent circumradius.

**G9d / I1 re-run on the corrected model** — the retraction below stands,
now for the right reasons:

| condition | RH-1 | dense | RH-1 relative |
|---|---|---|---|
| 1 tone, free field | 1.088 | 1.097 | 0.99× |
| 1 tone, walls | 1.136 | 1.094 | 1.04× |
| 5 tones, walls | 1.052 | 1.231 | 0.85× |
| 5 tones, walls + rainbow | 1.093 | 1.305 | 0.84× |

**First study of the plate-primary machine** (`fieldc plates`, receipt
`plates_*.json`). Six throat gates, phase-conjugate drive at the chamber
centre, the two plates as walls. MODEL numbers — the throat → aperture
transfer is the `HornModel` stub:

| condition | apertures | focus contrast | parasitic/main |
|---|---|---|---|
| 1 tone, free field, slots open | 3,688 | 9.3 | 1.05 |
| 1 tone, walls, slots open | 3,688 | 9.5 | 1.02 |
| 5 tones, walls, slots open | 3,688 | 7.0 | 1.00 |
| 1 tone, walls, slots closed | 256 | 14.8 | 1.00 |
| 5 tones, walls, slots closed | 256 | 7.3 | 1.00 |

Read it plainly: the plates do focus (focus contrast = peak intensity over
the mean of a ±3λ neighbourhood; not comparable to the desktop's whole-volume
amplitude gain), and open slots cost a third of the single-tone contrast. But
parasitic/main sits at 1.0 in every condition: a point-conjugate drive
between two facing apertures makes an axial standing wave whose λ/2 nodes
are equally deep, and neither more tones nor the rainbow selects one of
them. Holding *one* grain needs a trap signature (twin, vortex, bottle) or
face-to-face amplitude asymmetry — that is the next study, not a verdict on
the machine.

## Four bugs the gates caught

Recorded because they are the argument for gate-first development.

1. **Gor'kov closed form wrong by −3.** The literature's
   `F = 4πa³kE_acΦsin(2kz)` uses the Settnes–Bruus contrast factor (Φ_B = Φ/3)
   *and* a cos() pressure convention. Against a sin() field the correct form is
   `F = −(4/3)πa³kE_acΦsin(2kz)`. Getting this wrong **inverts the trap** —
   nodes become antinodes — and produces a plausible-looking levitation sim that
   is wrong everywhere. Verified by symbolic differentiation. Spec corrected.
2. **FDTD energy measured at the wrong point in the leapfrog cycle.** The
   discrete invariant pairs *consecutive half-step* velocities; squaring one of
   them drifts at O(dt²). Energy is now sampled after the velocity update and
   before the pressure update, where p^n, v^{n−1/2} and v^{n+1/2} are all in hand.
3. **The propagator was element-granular.** Elements are the discretization of
   the radiating surface; **gates** are what the electronics can drive. An
   element-granular operator over a 2.5M-point lattice is ~470 GB and was killed
   by the OOM killer. Gate-granular it is ~100 MB — and it is also the correct
   control granularity.
4. **Diff-PAT was mis-scaled by orders of magnitude.** H carries physical units,
   so |Hu| at unit drive is ~10³ while the nominal target is 1; Adam drove the
   solution toward zero chasing an unreachable target, scoring 0.20× against
   IBP's 10.77× — the "optimizer" made it 50× worse. Targets are now rescaled to
   what the aperture can deliver.

Two more were *metric* bugs, not physics bugs, and equally instructive: the
evaluation lattice initially included the transducer planes (where 1/r diverges,
so the field maximum is always a source), and the sidelobe metric flood-filled
to −6 dB and then measured the first voxel outside, which by construction
returns −6 dB regardless of beam quality.

## Open issues

- **G9b sidelobe bar not met and escalated, not ratcheted.** The spec's −10 dB
  was written without a reference configuration. Measured: −9.0 dB on-axis
  (16×16, f/0.62), −7.6 (f/1.24), −8.6 (24×24), −9.1 (32×32); −7.2 dB off-axis.
  The textbook −13.2 dB is a *continuous* aperture in the *far* field and does
  not apply to a discrete λ/2 array focusing in the Fresnel zone. Lateral
  placement is exact, so the solver is sound and the bar was wrong. Per §20 law
  L5 this reports informational and **needs an operator ruling**, rather than
  being edited quietly to whatever was measured.
- **Drive amplitudes are not physical in `fieldc focus`.** `maxAmplitude` is
  dimensionless there, so "holds 200 µm PLA: no" is not a real result. The
  force compiler's drives ARE in SI (aperture velocity, m/s) — see `fieldc
  levitate`, Round 8 — but the horn coupling behind them is a stub.
- **`I1` RETRACTED as originally stated — do not send it to the hardware lane.**
  The first pass measured RH-1's 24 channels at 10.8× focusing gain vs a
  512-channel array's 18.0× and read it as "24 DOF cannot focus". That number
  came from a **free-field, monochromatic, pressure-domain** model, which assumes
  away three designed-in precision levers of this machine:
  1. **The cavity is the aperture.** Rayleigh–Sommerfeld is open air; RH-1 is a
     closed high-Q cavity. Time-reversal focusing *through* the multipath means
     controllable DOF scale with the time–bandwidth product B·τ_reverb, not with
     channel count — published down to single-channel focusing in chaotic
     cavities. This is the same multi-bounce lever ranked first for imaging in
     §18, applied to transmit by reciprocity.
  2. **The spectrum is the address bus.** The printed holograms steer by
     frequency, so a chord is 24 DOF *per tone with per-tone aperture patterns*,
     not the same 24 DOF louder. A frequency-flat gate→element map models a plain
     array, not RH-1.
  3. **Force, not spot size.** For well-separated tones the cross terms
     time-average out, so per-tone Gor'kov potentials add — co-locate the main
     lobes and the sidelobes land elsewhere and average down.

  Now implemented: cavity walls (axial image sources) and per-tone rainbow
  gate→element weights in the machine model, and a force-level gate **G9d —
  parasitic-to-main trap depth ratio under an N-tone chord**. `fieldc broadband`
  reruns 24-vs-dense at **equal time–bandwidth** across four conditions.

  **Result — the original finding does not survive.** Parasitic/main trap depth
  ratio (lower is better), RH-1 24-ch vs a dense 200-ch array:

  | condition | RH-1 | dense | RH-1 relative |
  |---|---|---|---|
  | 1 tone, free field *(the old model)* | 1.088 | 1.097 | 0.99× |
  | 1 tone, walls | 1.088 | 1.073 | 1.01× |
  | 5 tones, walls | 1.055 | 1.231 | 0.86× |
  | 5 tones, walls + rainbow | 1.073 | 1.071 | 1.00× |

  24 channels are **within ±14% of a 200-channel array on the force-level
  metric in every condition** — nowhere near the 2× that would justify escalating
  a channel-count finding. **Nothing goes to the hardware lane.**

  Read this as a *retraction*, not as a new positive claim. Two honest caveats:
  the absolute ratio sits near 1.0 for **both** apertures, which may mean a
  single-point conjugate drive leaves comparably deep competing traps regardless
  of channel count (real physics — the λ/2 lobe structure) *or* that the metric
  does not yet discriminate; and the walls are axial image sources only (the two
  caps), not the full cavity. Distinguishing those needs a multi-point drive and
  T1 walls, and is not done.

## Principles alignment round

Four gaps against `replicator_principles.html` v1.0, all now built and tested.

**§3 — chord-valued drive.** The drive was `[Complex]`: one number per gate at
one implied frequency, expressing 2 of the 11 knobs in the §3 table and unable
to represent a chord at all. `ChordDrive` is a set of tones, each with its own
per-gate vector, plus orbital order — so "send a chord" and "frequency is the
address" are expressible rather than aspirational. Power is shared across tones,
not stacked.

**§5 — Dissolve, the missing verb.** *"Assemble and dissolve are the same drive
separated by one sign flip."* Now literally true: `.dissolve` conjugates every
gate amplitude. But the claim is about ENERGY FLOW, so it is tested as one — the
net acoustic intensity through a box around the workpiece must **reverse sign**
between the verbs. A sign flip that doesn't reverse the flux is a relabelled
pump.

**§6 — call-and-response.** The build was open-loop: solve once, emit, stop. The
giveaway was an asymmetry — the chord list was only ever an *output* of scan,
never an *input* to build. `CallAndResponse` makes it the input, the target and
the stopping test, with a "rings true" tolerance, a stall detector, and an error
metric where a **missing** resonance costs as much as a wrong one (otherwise a
workpiece ringing at nothing scores perfectly).

**§4 — `Z(r)`, the compiler's second output.** `SurfaceHologram` implements
`Z(r) = X₀ + M·Re{Ψ*ref·Ψobj}`, deliberately machine-agnostic per Memory &
Compute's "one toolchain, three back-ends". Tested by reconstruction: replaying
the reference must concentrate at the target, not merely produce a texture.

Three more bugs, all caught by writing the tests rather than the code:

12. **Twin-image convention in the hologram.** Storing the *diverging* wave a
    target would radiate puts the focus on the real twin image — measured 23 mm
    off target with no concentration at all (0.94× the plane mean). An emitting
    aperture must store the **converging** wave; then the focus lands on the
    |R|² term where it belongs.
13. **I expected dissolve to match assemble in magnitude.** It doesn't, and the
    reason is physics: conjugating the *drive* is not time-reversing the
    *problem* — the Green's function still radiates outward. A finite boundary
    recaptures only the fraction it subtends, which is exactly why the papers
    insist CPA needs conjugate control of both counter-propagating channels.
    Asserting equal magnitude would have been asserting a perfect absorber.
14. **A converging test case that diverged.** My loop test had the measured
    weight decreasing *past* the target, so the error grew and the loop correctly
    reported a stall. The test was wrong, not the loop.

## Audit round — what the gates found

**G5 (the keystone) now passes at 0.042 against a 0.05 bar**, and a resolution
sweep shows textbook second-order convergence — 0.159 / 0.088 / 0.057 / 0.042 at
λ/6, λ/8, λ/10, λ/12, against predicted (Δ)² ratios of 1.78 / 1.56 / 1.44. So the
residual is **FDTD grid dispersion in the reference solver**, not an error in the
propagator: T0 is validated, and every field slice, trap and particle in the
viewport rests on something now checked rather than asserted.

Four bugs surfaced getting there:

8. **Time-convention mismatch in G5.** T0 writes outgoing waves as `exp(+ikr)`,
   which is outgoing only under `exp(-iωt)`. The phasor extractor assumed
   `exp(+iωt)`, so the gate compared an outgoing wave against an **incoming**
   one; they differ by a distance-dependent phase `2kr` that no single complex
   scale can absorb, and the residual pinned at 0.989.
9. **Coverage asked the wrong question.** It summed `cos θ` over gates that could
   see a *location* — but every interior point is visible to some gate, so it
   returned ~1 everywhere and reported **0.0% of the volume unobserved for a
   12-gate ring**. Specularity is about *orientation*: a facet is measurable only
   if some (Tx,Rx) bisector is parallel to its normal. Rewritten as bisector
   coverage of the orientation sphere, with the acceptance angle derived from
   facet size (`asin(λ/2D)`) rather than picked. Honest answer for this ring:
   **coverage p10 0.24, median 0.37, p90 0.48** — it catches about a third of
   facet orientations.
10. **G10 truncated a joint fit.** Each chord's amplitude was solved with the
    others present, so dropping chords leaves the survivors mis-weighted — the
    error curve came out non-monotone (K2 worse than K1, K16 worse than K8),
    which reads as an extractor fault but is an invalid comparison. Refitting per
    subset makes it exactly monotone.
11. **G5's domain was fixed in cells, not wavelengths.** Refining the grid shrank
    the physical domain, moving the sample annulus toward the source and sponge —
    a resolution sweep read non-monotonically (0.130 at λ/8 but 0.076 at λ/16)
    and would have been misread as the propagator failing at high resolution.

## Known defects in the scan pipeline — do not trust these outputs yet

1. ~~Chord amplitude fit does not reconstruct.~~ **Fixed** — shifted QR,
   model-order sweep, DC-artifact rejection. G18 passes at 0.122.
2. ~~Coverage is too generous.~~ **Fixed** — see the audit round above.
3. **G14a/G14b still report IoU 0.** The reconstruction is a reflectivity image
   thresholded at 0.35 of peak, which does not align with the object's occupancy
   at this scan resolution. The gates are informational by design (a bar there
   would reward hallucination), but the numbers are not yet meaningful.
4. **Drive amplitudes are still not in SI**, so no force or stiffness number is
   quotable and G8 stays blocked.

## Three more bugs the gates caught this round

5. **Scattering matrix was a Gram matrix.** The scan summed all drives into one
   record set, which destroys the per-drive structure. `S = Σᵢdᵢdⱼ` is symmetric
   *by construction*, so the reciprocity QC read exactly 0.0000 and was testing
   nothing. Now keeps `S[rx][tx]` per drive; reciprocity reads 0.001 and is a
   real measurement.
6. **FDTD ran at λ/2.1.** The scan drove 40 kHz on a 4 mm grid — well below the
   λ/5 the spec itself requires (§12), so the propagating wave was numerically
   garbage. The drive frequency now follows the grid (`c/8dx`).
7. **Unshifted QR cannot resolve complex-conjugate eigenvalues.** The pencil's
   `Z` is real, so its eigenvalues come in conjugate pairs, and unshifted QR
   provably stalls leaving 2×2 blocks — reading the diagonal returned only real
   numbers, so **every chord came out at f = 0 Hz**. Now reads the
   quasi-triangular form and solves each 2×2 block's quadratic.

## Toolchain constraints (verified on this machine)

- **No Xcode**, CommandLineTools only. SwiftUI/Metal/MetalKit still compile.
- **`XCTest` is unavailable** without Xcode, so `swift test` cannot build. The
  suite runs through a ~60-line harness in `FieldCore/Testing` via `fieldc test`.
  Consequence: tests run anywhere Swift does, including bare CI containers.
- Metal shaders must be compiled **at runtime** from source
  (`makeLibrary(source:)`); the offline `metal` compiler needs Xcode. This also
  makes kernels hot-reloadable.

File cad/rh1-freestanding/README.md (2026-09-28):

# RH-1 free-standing — generated CAD

Everything in this folder is **generated by the digital twin** from one
parametric design (`twin/Sources/FieldCore/CAD/RH1Design.swift`). Do not edit
these files; change the design and regenerate. What each number is, where it
came from, and which conflicts between the website, the specification and the
old Blender model were resolved how: [`twin/CAD.md`](../../twin/CAD.md).

| file | what | made by |
|---|---|---|
| `rh1.step` | B-rep STEP assembly, 92 named, coloured components (152 solids — each contrawound winding is eleven 4-turn bodies). Opens in Fusion 360, SolidWorks, FreeCAD, Onshape as components. mm, floor z = 0, front +x. | `fieldc cad step` (CadQuery / OpenCascade) |
| `rh1_step_report.json` | per-part B-rep volume vs the twin's mesh volume — gate G-STEP | same |
| `rh1_general_arrangement.svg` / `.png` | half-section elevation to scale + the plate face in plan | `fieldc cad drawing` |
| `BOM.md` | bill of materials: part, material, register, volume, mass | `fieldc cad bom` |
| `rh1_params.json` | the full design: stack, faces, horn/cone profiles, every sunflower site and slot, provenance, reconciliation, part volumes | `fieldc cad params` |
| `renders/` | iso, front, section, section-iso, detail, plate, storage, top | `fieldc cad render --all` |
| `rh1_freestanding_rev3.blend` | render model for the deck / site: the same geometry with spec §8 finishes, assembly collections, rev2 camera and lights, a quarter section cutter wired in (disabled) | `Tools/rh1_blend.py` on the OBJ export |

Regenerate everything (from `twin/`):

```sh
swift build -c release
./.build/release/fieldc cad check --receipt
./.build/release/fieldc cad export --out cad-out
./.build/release/fieldc cad step --out ../cad/rh1-freestanding/rh1.step
./.build/release/fieldc cad render --all --out ../cad/rh1-freestanding/renders
blender -b --python Tools/rh1_blend.py -- cad-out/rh1.obj ../cad/rh1-freestanding/rh1_freestanding_rev3.blend
```

Base contents (reservoir, graphite bay, power, compute, pump, cartridge circle,
optical-stem head, touch UI) are **envelopes only** — the documents list them
but dimension none of them.

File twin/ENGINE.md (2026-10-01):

# The engine plan — open air, physics-limited plates, linear-first compute

Written 2026-10-01 after the operator's decisions below. This is the plan the
twin is built to from Round 12 on. The README's rounds report what was built
and measured against it.

## Decisions (operator, 2026-10-01)

1. **Chamber: keep the cylinder, drop the glass.** Two Ø410 mm plates, 460 mm
   apart, with open air between them, as the first prototypes will be. The
   glass-cylinder model (`CylinderCavity`, Rounds 7–11) stays as an option,
   not the default.
2. **Plates: specified by physics, not by "three horns per face".** Each plate
   is a holographic acoustic surface; the design target is the point where
   physics (wavelength, bandwidth, the air's nonlinearity) limits it, not the
   engineering.
3. **Compute: make the engine efficient before spending compute on it.** Heavy
   runs stay at `taskpolicy -c utility`, sequentially.

## Why the twin was heavy

A mold run as of Round 11 (40 tones, glass chamber):

| stage | what it does | why it is heavy |
|---|---|---|
| fields | each tone's six gate fields (p and ∇p) at ~60,000 grid points, each a sum of 10,000–20,000 cavity modes | ~10¹⁰ mode evaluations; rebuilt from scratch by every command |
| compile | Adam, 400–800 sweeps; every sweep evaluates the force at all 60,000 points × 40 tones and its gradient | ~1 GB of rows streamed through the CPU in double precision per sweep |
| powder | 3,000 grains × 16,000 time steps | 48 M steps |
| scan | 90 frequencies × the field build again, on the image grid | the field build × 90 |

Nothing is reused between runs, and only the field build uses the GPU.

## The one fact the engine is built on

The air between the plates is linear. The field is a fixed linear response to
the drive, and the time-averaged force on a small grain is a quadratic form in
the drive, U(x) = Σ_f g_fᴴ K_f(x) g_f. So:

* the response is computed, not simulated: in open air it is closed-form
  (piston elements plus their images in the plates);
* every objective the compiler uses — the lift at a site, the depth of a well,
  the most any other point can lift — is a quadratic form in the drive, so the
  compile is linear algebra on a few hundred numbers, not a search over a grid;
* overdamped powder only slides downhill, so where it ends is a property of the
  landscape (its basins), not of a trajectory;
* a scan is the transpose of the same response (the matched filter).

## The plates, limited by physics

For the RH-1 geometry: Ø410 mm plates, 460 mm apart, a ±12 mm work volume at
the mid-plane, 230 mm from each plate.

| limit | set by | number |
|---|---|---|
| finest pattern | λ/2; finer detail does not propagate | 2.5 mm at 70 kHz, 4.3 mm at 40 kHz |
| channels that matter | the independent field patterns a ±12 mm volume can hold, ~(kR)², from the ~25 % of directions two Ø410 plates cover | ~60–200 per tone |
| layout | sparse aperiodic array: a Vogel spiral (golden angle) puts every element at a unique radius, so no grating lobes | already the cap-and-stack ruling |
| element size | ≲ λ at the top frequency, so an edge element still reaches the centre (it sees it 42° off its normal) | ~5 mm at 70 kHz |
| bandwidth | pulses and range resolution | 30–100 kHz → 2.5 mm |
| loudness | the air turns nonlinear (shocks within centimetres) | ~160–165 dB |
| gain | at fixed power the focal pressure grows as √N with the channel count | 200 channels vs 6: ~6× |

The open air gives up the glass's resonant gain (2.5–6×, Round 8); the channel
count wins it back, and the field is clean: no glass speckle, fast settling,
less thermal drift. A full λ/2 grid would be ~7,000–22,000 elements per plate;
the study below finds how many independently driven elements are worth having.
Space–time coding (1-bit switching with timing, as in the PCB holographic
transducer paper §9.3) gives each element amplitude and phase cheaply.

## The engine

1. **Response (`PlateArray`, `OpenAirField`).** Two plates of N elements each on
   a Vogel spiral; each a baffled piston (far-field directivity 2J₁(ka sin θ)/(ka
   sin θ)); the plates reflect with R (images to order K; R = 0 is free field).
   Matrix-free on the GPU: one pass gives p and ∇p at any points for a drive,
   a second gives the gradient of any weighted sum of U with respect to every
   element's drive. No rows are stored, so N can be thousands. A CPU reference
   in Double backs every kernel.
2. **Compile.** The same objectives as the glass chamber (trap uniqueness; the
   sieve's lift contrast with sideways traps and fair landing funnels) on any
   field operator. Next: generalized eigen-solves on the quadratic forms (the
   ratio of two quadratic forms is maximised exactly by a generalized
   eigenvector), with active sets for the "anywhere else" maxima, so a compile
   is a handful of small solves.
3. **Matter.** Basin maps for overdamped powder: every grid cell points to its
   steepest descent in U_eff = PU + mgz; following the pointers gives the
   destination of every start at once. Recirculation is a closed form: grains
   that fall out re-enter at the top, so each site's final share is its direct
   share plus the fallen fraction times the top row's distribution. Particle
   stepping stays as a check; Ø200 µm beads, which swing, stay time-stepped.
4. **Scan and reading.** The matched filter is the response transposed:
   single-input multiple-output, full multiple-input multiple-output, and
   random-chord illumination with coincidence processing are different slices
   of one operator, so they can be compared directly. Reading with light
   (schlieren or interferometry strobed at the drive; 160 dB puts ~0.7 rad on a
   laser crossing 20 mm of the work volume) measures the real field and so the
   real response, which calibrates the twin; a camera reads the matter.
5. **Precision and hardware.** fp32 for computing (sums over many elements
   cancel near nodes, and forces live near nodes), fp16 for anything stored,
   fp64 for small solves. The model is good to ~0.1–1 % (temperature alone turns
   phases ~50° per kelvin at 70 kHz across the chamber), so precision beyond
   ~1e-4 is wasted. The Neural Engine is the home for always-on fixed operators
   (live imaging, previews) once the machine runs continuously; per update it
   takes ~3× less energy than the GPU (measured on EqProp, 2026-09-23).

## Gates and studies, in order

| id | what | pass |
|---|---|---|
| G-A1 | `OpenAirField` GPU vs CPU reference, p and ∇p, with images | rel. L2 < 1e-4 |
| G-A2 | piston element vs the numerical Rayleigh integral over its face | < 1 % |
| G-A3 | matrix-free gradient vs finite differences of U | < 1e-3 |
| G-B0 | basin map vs the particle simulation on the same field | capture shares agree to a few % |
| S1 | channel sweep: N per plate = 3, 12, 48, 192, 768; 1 and 3 tones. Single-tone trap uniqueness at the centre, the ring sieve's lift contrast, capture and evenness, the drive a PLA grain needs | the knee in N |
| S2 | the sieve mold in open air with the knee N: ring, tetrahedron frame | G-M1, G-M2 |
| S3 | scan in open air (SIMO, MIMO, coded) and the replicate loop: scan → read the shape → mold → rescan | G-R1–3 |
| later | light readout (simulated schlieren = the on-screen rendering), pulse verbs (time-reversal focusing; toroidal pulses as tag-and-hold), the Neural Engine | — |

## What the CAD session needs from this

The plate is N independently driven elements on a Vogel spiral, each ≲ 5 mm,
broadband over 30–100 kHz, with a stiff face; N comes from S1. The two plates'
spacing (460 mm) and diameter (410 mm) are the inputs the study uses. If they
change, the numbers above change with them.

## Candidate referents (from the toroidal-engine frame), graded

* "Implosion": converging, time-reversed wavefronts concentrate wave energy
  as well as an aperture allows. Established; a pulse verb in S3/later.
* "Dual toroid": two facing emitters whose fields meet at the mid-plane; the
  vortex-ring streaming that forms around foci. The geometry is ours; streaming
  is not modelled yet.
* "Golden ratio": the aperiodic golden-angle layout suppresses grating lobes
  (established, adopted); golden-ratio tone spacing is testable in S1.
* "Embedding in the array": no handle the twin can test.

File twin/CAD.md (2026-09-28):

# RH-1 solid model — the CAD inside the twin

The free-standing RH-1 as a parametric solid model, built by FieldCore with no
dependencies, rendered by the twin's Metal pipeline, gated like the physics,
and exported to STL / OBJ / STEP. The physics preset for the plate-primary
machine (`RH1Freestanding`) reads its apertures from this model, so the CAD
and the simulation cannot drift apart.

Source files: `Sources/FieldCore/CAD/` (kernel, design, model, gates, exports),
`Sources/FieldGPU/SolidRenderer.swift` + `Shaders/solid.metal` (rendering),
`Tools/rh1_step.py` (B-rep STEP via CadQuery).

## Use it

```sh
swift build -c release
./.build/release/fieldc cad info --reconciliation   # stack, provenance of every number, conflicts
./.build/release/fieldc cad check --rules --receipt # CAD gates + 25 design rules
./.build/release/fieldc cad render --all --out renders/    # iso, front, section, section-iso, detail, plate, storage, top
./.build/release/fieldc cad render detail --light --door open detail.png
./.build/release/fieldc cad export --out cad-out    # STL per part, rh1.obj+mtl, params, BOM, drawing
./.build/release/fieldc cad step --out cad-out/rh1.step   # B-rep STEP assembly (needs CadQuery)
./.build/release/FieldCompilerApp                   # Machine tab: orbit, S = section, 1–5 views
```

Options: `--preview | --fine` (tessellation only — the design is identical at
every detail level), `--door open|closed|<deg>`.

## What is modelled — 92 parts

| assembly | parts | notes |
|---|---|---|
| body | bottom closure, lower body tube 0–1060, top band, crown, crown cap, LED ring | 4 mm anodized shells, Ø460 × 1650 |
| plate.top / mid-up / mid-down / deck | face plate, carrier ring, gyroid horn, copper inner cone, 3 throat piezos, rim electronics | four radiating faces; the middle assembly is two back-to-back stacks |
| torus.top / middle / deck | hollow former Ø290/Ø60, contrawound winding pair (CW feed A, CCW feed B) | 44 turns each, two independent feeds (R5) |
| bore | collars top / middle, deck feed tube | Ø12 clear, Ø14 collar |
| storage | chamber liner Ø400 | 420 → 936 |
| enclosure | rear glass Ø444 (fixed), front glass Ø464 (rotating), end-bands, 2 V-groove tracks, 6 V-rollers | door is a parameter |
| arcade | 7 slim columns + RX/status strips | rear 180°, 30° pitch |
| photonic | 6 optically-addressed bay tiles | between the columns |
| base / crown | intake filter, reservoir, graphite bay, PSU, compute, pump, cartridge circle, optical-stem head, touch UI | **envelopes only** — dimensioned nowhere |

The face plate is the part that carries the design: a Ø410 × 12 disc with a
Ø14 collar hole, twelve equiangular spiral slots (α = 76.05°, r 32.6 → 189.7,
width 2.8 → 6.0 mm, round ends), and the drilled sites of a 380-site
golden-angle sunflower as biconical micro-horns (face radius 1.054 + 0.00981·r
mm, throat half of it). All four faces share one world-frame pattern, so facing
plates are mirror parts with opposite intrinsic handedness (spec §6.0).

## Where every number comes from

`fieldc cad info` prints the full provenance list; each item carries a
register — **committed** (a paper commits to it), **site** (measured off an
etherworks.io to-scale figure), **derived**, **resolved** (a conflict settled in
code, below), or **assumed** (specified nowhere; a sized choice). Sources win
in this order when they disagree:

1. Mechanical Construction §3c (2026-08-03) — the plate stack, worked exactly.
2. etherworks.io "How it works" (2026-08-10) — FIG. 1 of *The machine* is drawn
   at exactly 0.48 px/mm (body 220.8 × 792 px = Ø460 × 1650), so its rectangles
   are dimensions; FIG. 2 of *The plate* is "drawn from the same math as the
   real one" — its 380 dots and 12 slot paths were fitted (golden angle
   137.508°, cot α 0.2483, hole radius law to 0.005 mm).
3. Hardware Specification RH-1 v0.4 (2026-07-30) — §3, §5, §8.
4. `lpoh/cad/rh1_freestanding_rev2.blend` — stale; used only where nothing
   newer exists (shell band heights).

## Reconciliation — conflicts resolved in code, not silently

| topic | papers | site | model | why |
|---|---|---|---|---|
| Middle plate | spec §8: one plate 1048–1060, torus + horn below | two plates flanking one torus | faces at 1060 (up) and 936 (down), mirrored about the 998 torus | a 12 mm plate cannot carry two back-to-back cap stacks |
| Storage deck & chamber | deck 655, chamber Ø400 × 385, base ~650 | deck 420, chamber 425–930, base 0–400 | deck face 420, chamber 420–936, deck torus 365 | the spec's numbers overlap its own middle stack (655 + 385 > 936) |
| Throat piezos vs bore | 3 × Ø25 (assumed) on r = 18 | — | 3 × Ø20 on r = 18; throat Ø36 and every horn number kept | Ø25 on r = 18 reaches r = 5.5 — inside the Ø12 bore |
| Bore collar | Ø12 bore + collar | Ø12 | Ø12 clear, Ø14 × 1 mm collar | a collar needs a wall |
| Face pattern | ~380 Vogel sites + 12 slots, "slots cut through" | dots drawn over slots | sites whose opening would cut a slot web are left to the slot void | the slot is already open there |
| Side panels | plan B (phononic); photonic note = DRAFT | six optically-addressed panels, baseline | six photonic tiles, EM only | site is newest; note is not yet a ruling |
| Arcade columns | desktop 40×20; free-standing "slim", no section | ~5 mm gaps | 18 × 10 at r 206–216 | 40×20 does not fit the 13 mm annulus |
| Canonical model | spec §8: rev2.blend | — | this model supersedes it | rev2 predates the Ø12 bore |
| Touch UI | 7″ "at standing eye height" | — | surface-mounted on band/crown | no flush shell surface there |

## What the CAD found — for the papers

These came out of building the geometry, not out of reading it:

1. **Only 128 of the 380 sunflower sites can be drilled.** 252 fall inside a
   slot or within its 0.8 mm web. The twelve arms are tightly wound (α = 76°,
   1.13 turns), so along any ray the arms repeat every 13.9 % of radius and
   their clearance bands cover roughly three-quarters of the face. Site FIG. 2
   draws the dots over the slots without resolving this.
2. **The slots are the acoustic aperture.** Per face: slots 34,600 mm² open,
   micro-horn faces ~2,700 mm² (throats ~680) — 12.8×. The papers call the
   slots voids in the conductor with porous gyroid behind; if so they radiate,
   and "too sparse to block the sound" undersells them — they are 93 % of the
   open area and a spiral line-source array, not a sunflower. **Open question
   for the operator:** are the slots acoustically open, or dielectric-filled?
   `RH1Freestanding` carries both (`--slots-closed`).
3. **"21 × 34" is the mid-field reading.** Nearest-neighbour parastichies of the
   380-site field run 13 × 21 (inner third), 21 × 34 (middle), 34 × 55 (rim) —
   the paper's claim holds where it says, and the rim reads the next pair.
4. **The throat piezos do not fit around the bore** as specified (item 3 of the
   reconciliation). Design rule DR1 now pins ≥ 0.5 mm.
5. **Mass ≈ 69 kg, not ≈ 50.** Shells 28.9 kg (the 7 kg storage liner and the
   base closure are not in the spec's "~20"), plates + carriers 16.1 kg (four
   faces, the spec counted three), glass 6.4 kg (spec 6.5 ✓), hollow formers +
   windings ~9 kg. Placeholders excluded.
6. **Horn geometry checks out:** meridian arc 187.4 mm (mech §3c: ≈187),
   mouth:throat 11.2:1, fold 9.4:1.

## Validation

`fieldc cad check` (receipt in `Receipts/cad_*.json`):

| gate | measures | bar |
|---|---|---|
| G-CAD1 | every part a closed, outward-oriented solid (edge census on shared vertices) | 0 failures |
| G-CAD2 | mesh volume vs closed form, 77 parts | < 1 % |
| G-CAD3 | 25 design-rule clearances (piezo/bore, winding layers, horn, slots, glass, rollers, columns, tiles, …) | all ≥ minimum |
| G-CAD3b | sampled interference between every pair of neighbouring parts | none |
| G-CAD4 | dimension audit vs spec/site (14 checks) | < 0.1 mm |
| G-CAD5 | 21 × 34 parastichies present | present |
| G-CAD6 | horn arc length vs mech §3c | < 1 mm |
| G-CAD7/8 | mass budget; open area slots vs micro-horns | informational |

`fieldc cad step` adds **G-STEP**: every B-rep part's exact OpenCascade volume
against the Swift mesh volume — two independent geometry kernels (1.5 % solids,
3 % swept windings; worst part at 0.43× its tolerance). Re-importing the STEP
gives 152 valid solids, 0 invalid.

Unit tests (`fieldc test`) cover the triangulator (60-hole disc exact), revolve
/ sector / torus / extrusion / sweep closure and volumes, the interference test
itself (overlap caught, touching not), the stack, and a model-wide rule check.

## Kernel notes

- Zero dependencies. Every generator builds shared-index topology, so
  watertightness is a property of the construction, which the edge census
  then verifies (it does not weld floats to pass).
- Plate faces are one polygon with ~390 holes; triangulated by a flat-array
  port of Mapbox earcut, sharing vertices with the hole walls.
- The drilled-hole set is decided against a fixed fine slot centreline — it
  once depended on display tessellation, which a unit test caught.
- Wire polygons use an area-equivalent circumradius, so an 8-sided winding
  carries the copper cross-section of the round wire.
- OCCT will not sweep one closed 44-turn periodic spine into a valid solid;
  each STEP winding is eleven valid 4-turn bodies meeting end to end.
- Rendering: section cuts are fragment discards (a wedge, optionally a height
  band); back faces seen through a cut are painted as hatched section caps;
  glass never caps. 4× MSAA offscreen, same pipeline as the live Machine tab.

## Not modelled / open

The gyroid lattice itself (the horn is its envelope), the V-groove
construction of the micro-horn mesh (modelled as biconical holes), the EBG
terminal layer, the photonic tiles' write projector (OPEN in the photonic
note), gaskets, interlock and detents, wiring, and everything in the base
beyond envelopes. The plate-primary acoustic preset's throat → aperture
transfer is a labelled stub (`HornModel`), so every force it produces is a
model number.

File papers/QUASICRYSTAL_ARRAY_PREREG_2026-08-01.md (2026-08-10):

# Pre-registration: Icosahedral-quasicrystal volumetric array vs periodic vs random

Date frozen: 2026-08-01 (before any simulation run).
Lane: replicator / field compiler.
Origin: Winter audit Addendum 3 (memory
`project_winter_phase_conjugation_audit_2026-07-30.md`) — the
crystallographic-restriction fork: A₅ order in flat 3D forces
φ-inflation quasiperiodicity; candidate canonical 3D extension of the
cap's 2D Fibonacci/Vogel mesh (R1–R12 rulings).
Sim: `scripts/quasicrystal_array_prereg_sim.py` (this doc's RESULTS
section is empty until the sim has run once; nothing above the RESULTS
heading may be edited after the first run).

## Question

For a volumetric point set of N isotropic monochromatic sources (Born
equivalent: weak scatterers) phased to steer a far-field beam, does an
Ammann–Kramer icosahedral quasicrystal arrangement (a) suppress grating
lobes like a random array, and (b) beat the random array on *isotropy*
of sidelobe performance across steering directions?

## Arms (point sets, all ~N=800 in the unit sphere, equal density)

- **SC** — simple-cubic lattice, spacing tuned to hit N in sphere.
- **FCC** — face-centred-cubic lattice, same tuning (second periodic
  arm, so a periodic-arm failure can't be blamed on SC being a strawman).
- **RND** — uniform (Poisson) points in the sphere; 3 seeds
  (20260801, 20260802, 20260803), each reported.
- **QC** — Ammann–Kramer icosahedral quasicrystal by cut-and-project:
  Z⁶, par/perp stars = icosahedron vertex vectors (1, φ, 0)-family and
  their Galois conjugates (φ → −1/φ), acceptance window = perp-space
  zonotope (rhombic triacontahedron) with generic phason offset
  γ = (0.0131, 0.0237, 0.0347, 0.0453, 0.0561, 0.0673); global scale
  tuned to hit N in sphere.

## Physics and metrics (frozen)

Far-field array factor, conjugate phasing at steering direction u:
F(v) = (1/N) Σ_j exp(i k r_j·(v−u)); |F(u)| = 1 by construction.

- Characteristic spacing d_c = (V_sphere/N)^{1/3}, identical across
  arms by construction. Three wavelength regimes s = d_c/λ ∈
  {0.6, 1.0, 1.6} (sub-grating, onset, super-grating).
- Steering set: 48 Fibonacci-sphere directions. Evaluation grid: 16384
  Fibonacci-sphere directions.
- Main-lobe exclusion cone: angle < 3λ/D around u, D = 2·max|r_j|.
- **PSL(u)** = 20·log₁₀ max_{v outside cone} |F(v)|  [dB, ≤ 0].
- Per arm & regime: **median PSL** over the 48 steerings (lobe
  suppression), **std PSL** and **worst-case (max) PSL** (isotropy).

## Frozen predictions

- **P1 (control / sanity):** at s ≥ 1.0 the periodic arms (SC and/or
  FCC) show grating lobes: worst-case PSL > −3 dB at some steering.
  QC and RND stay below −3 dB worst-case at s = 1.0.
- **P2 (lobe suppression):** QC median PSL is within 3 dB of the RND
  median PSL in every regime. (If QC shows strong Bragg lobes that
  break this, the Winter-salvage quasicrystal candidate **dies** and
  the 2D-only Fibonacci-mesh ruling stands unchanged.)
- **P3 (isotropy — the actual bet):** std of PSL across steerings is
  smaller for QC than for every RND seed in every regime, and
  worst-case PSL for QC is no worse than the worst RND seed.

Decision rule: P2 AND P3 pass in ≥ 2 of 3 regimes → adopt the doctrine
sentence "A₅ on the boundary, φ-quasicrystal in the volume" as a
*candidate* geometry ruling for volumetric scatterer/perforation
layouts (still subject to a full-wave check in the compiler). Any P2
fail → candidate dead, log the negative. P2 pass + P3 fail → QC is
merely "as good as random," no reason to prefer it except determinism;
log as neutral.

## Declared limitations

Linear, far-field, isotropic point sources, Born single-scattering, no
element factor, no multiple scattering, no enclosure walls. This is an
array-factor screen, the same fidelity class as the 07-30 φ-comb PSR
screen — a gate for compiler-level follow-up, not a chamber verdict
(cf. `feedback_mdd_envelope_is_not_chamber_verdict`).

---

## RESULTS (append-only below this line; frozen text above)

Run 1, 2026-08-01, first execution of the sim after freezing.
Raw JSON: scratchpad `qc_prereg_results.json`; console table below.
Sanity: RND sidelobe floor matches the analytic peak-of-M-samples
prediction 10·log₁₀(ln M / N) ≈ −19.2 dB; SC/FCC grating lobes appear
exactly at s ≥ 1.0 as required. (numpy emitted spurious Accelerate
matmul RuntimeWarnings on macOS; outputs contain no NaN/Inf.)

| arm | s=0.6 med/std/worst | s=1.0 med/std/worst | s=1.6 med/std/worst |
|-----|---|---|---|
| SC  | −6.5 / 8.7 / −0.1  | −1.4 / 3.1 / −0.03 | −0.5 / 0.7 / −0.07 |
| FCC | −5.3 / 6.5 / −0.1  | −1.7 / 4.4 / −0.03 | −0.6 / 1.4 / −0.00 |
| QC  | −6.9 / 1.9 / −5.9  | −3.7 / 2.4 / −1.0  | −2.9 / 1.4 / −1.1  |
| RND (3 seeds, range) | −19.8…−19.2 / ≤0.8 / ≤−18.1 | −19.2…−19.1 / ≤0.6 / ≤−17.3 | −19.2…−18.9 / ≤0.7 / ≤−17.4 |

**P1: PASS for periodic arms** (grating lobes at s ≥ 1.0, worst ≈ 0 dB)
**but the QC sub-condition FAILS** — QC worst at s=1.0 is −1.0 dB, i.e.
QC itself grows near-full-strength lobes past the grating onset.
**P2: FAIL in all three regimes** — QC median is 12–16 dB *worse* than
random, not within 3 dB.
**P3: FAIL** — QC std (1.4–2.4 dB) exceeds every RND seed (≤ 0.8 dB).

**Verdict per frozen decision rule: the candidate is DEAD.** The
"A₅ on the boundary, φ-quasicrystal in the volume" doctrine sentence is
rejected. Physical reading (post-hoc, marked as such): quasicrystals
have *pure-point* diffraction — that is literally how Shechtman found
them — so an AK array concentrates sidelobe energy into sharp
icosahedrally-arranged Bragg lobes instead of spreading it into a
diffuse floor. Aperiodicity alone is not the virtue; **spectral
diffuseness** is. This *refines* rather than threatens the 07-30 2D cap
ruling: the Vogel/golden-angle mesh is aperiodic *with a diffuse
spectrum* (no Bragg peaks), which is why it works — it is not a
quasicrystal. Candidate for a future pre-reg (NOT tested here): 3D
blue-noise / Poisson-disk point sets as the volumetric extension —
random's diffuse spectrum plus a minimum-spacing guarantee. Winter
salvage #2 (quasicrystal volumetric geometry) is now measured-dead;
salvage #1 (χ²-mixing φ-comb closure) remains open, blocked on the
nonlinear lane.

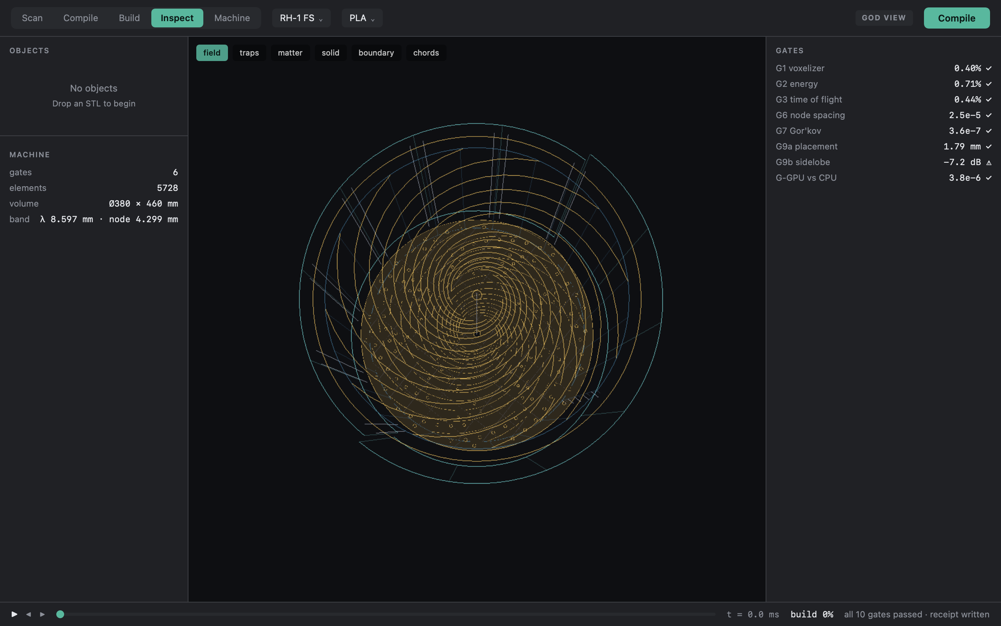
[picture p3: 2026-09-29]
twin/shots/gate-report.dark.png

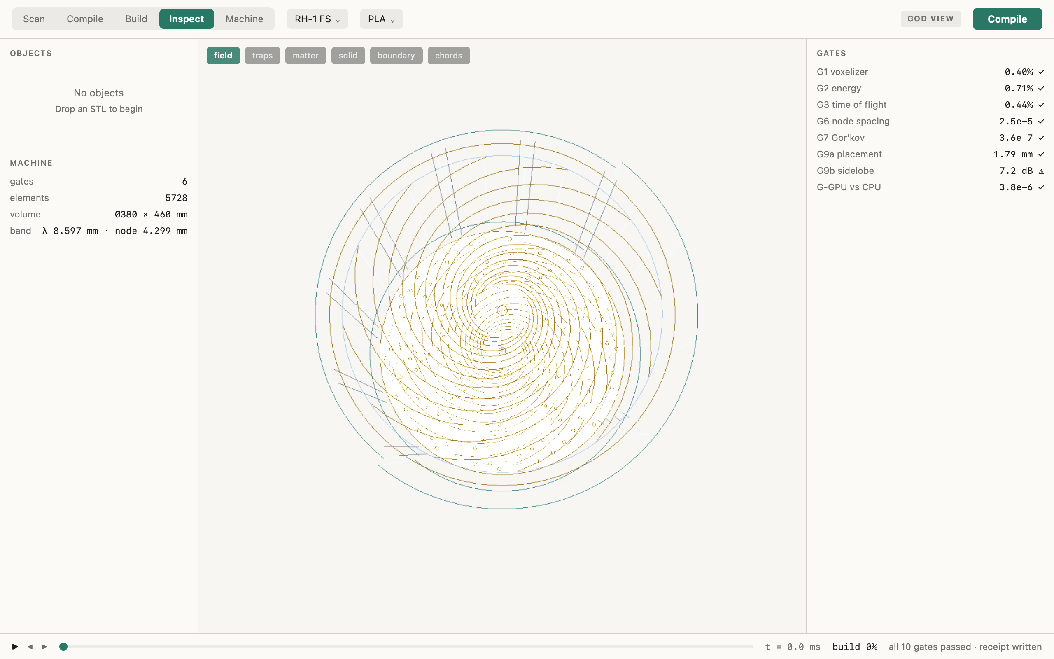
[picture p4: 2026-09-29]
twin/shots/gate-report.light.png

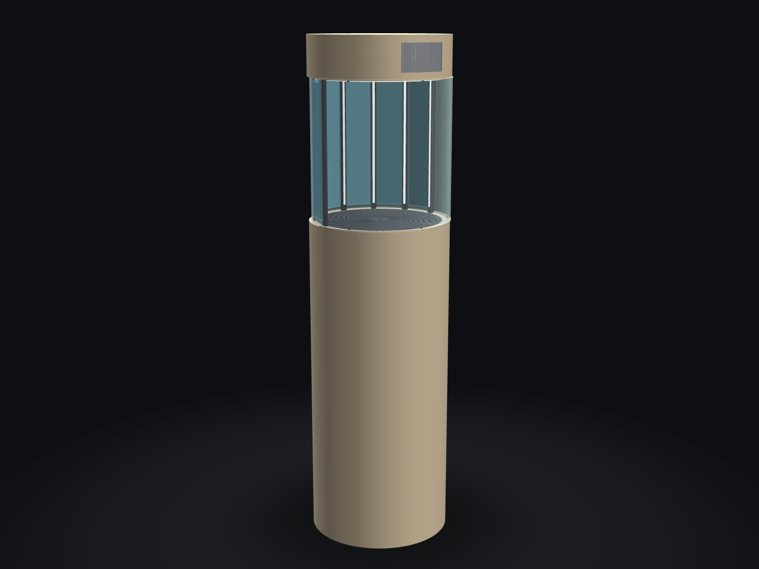
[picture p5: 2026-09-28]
cad/rh1-freestanding/renders/rh1_iso.png

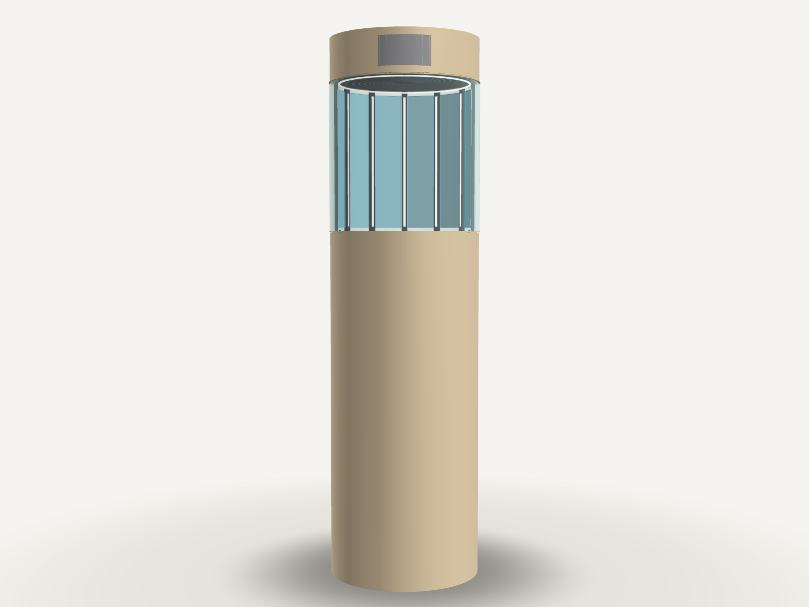
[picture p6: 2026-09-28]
cad/rh1-freestanding/renders/rh1_front.light.png

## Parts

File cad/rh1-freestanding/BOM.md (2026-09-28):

# RH-1 bill of materials (generated)

Generated by `fieldc cad bom` from `RH1Design` — edit the design, not this file.

| assembly | part | material | register | volume cm³ | mass kg |
|---|---|---|---|---:|---:|
| body | bottom closure | Al 6063, champagne anodized | committed | 664.5 | 1.794 |
| body | lower body tube | Al 6063, champagne anodized | committed | 6049.1 | 16.332 |
| body | top band | Al 6063, champagne anodized | committed | 401.0 | 1.083 |
| body | crown | Al 6063, champagne anodized | committed | 320.8 | 0.866 |
| body | crown cap | Al 6063, champagne anodized | committed | 664.5 | 1.794 |
| storage | storage chamber liner | Al 6063, champagne anodized | resolved | 2618.6 | 7.070 |
| plate.top | face plate top | Al 6082, dark machined | committed | 1148.3 | 3.100 |
| plate.top | carrier ring top | Al 6063, champagne anodized | resolved | 341.1 | 0.921 |
| plate.top | gyroid horn top | Graded ceramic gyroid (alumina, ρ_rel 0.25) | committed | 321.3 | 0.317 |
| plate.top | inner cone top | Copper | committed | 2.9 | 0.026 |
| plate.top | throat piezo top.1 | PZT-8, silvered | resolved | 2.5 | 0.019 |
| plate.top | throat piezo top.2 | PZT-8, silvered | resolved | 2.5 | 0.019 |
| plate.top | throat piezo top.3 | PZT-8, silvered | resolved | 2.5 | 0.019 |
| plate.top | rim electronics top | FR4 + electronics | derived | 236.4 | 0.437 |
| plate.mid-up | face plate mid-up | Al 6082, dark machined | committed | 1148.3 | 3.100 |
| plate.mid-up | carrier ring mid-up | Al 6063, champagne anodized | resolved | 341.1 | 0.921 |
| plate.mid-up | gyroid horn mid-up | Graded ceramic gyroid (alumina, ρ_rel 0.25) | committed | 321.3 | 0.317 |
| plate.mid-up | inner cone mid-up | Copper | committed | 2.9 | 0.026 |
| plate.mid-up | throat piezo mid-up.1 | PZT-8, silvered | resolved | 2.5 | 0.019 |
| plate.mid-up | throat piezo mid-up.2 | PZT-8, silvered | resolved | 2.5 | 0.019 |
| plate.mid-up | throat piezo mid-up.3 | PZT-8, silvered | resolved | 2.5 | 0.019 |
| plate.mid-up | rim electronics mid-up | FR4 + electronics | derived | 236.4 | 0.437 |
| plate.mid-down | face plate mid-down | Al 6082, dark machined | committed | 1148.3 | 3.100 |
| plate.mid-down | carrier ring mid-down | Al 6063, champagne anodized | resolved | 341.1 | 0.921 |
| plate.mid-down | gyroid horn mid-down | Graded ceramic gyroid (alumina, ρ_rel 0.25) | committed | 321.3 | 0.317 |
| plate.mid-down | inner cone mid-down | Copper | committed | 2.9 | 0.026 |
| plate.mid-down | throat piezo mid-down.1 | PZT-8, silvered | resolved | 2.5 | 0.019 |
| plate.mid-down | throat piezo mid-down.2 | PZT-8, silvered | resolved | 2.5 | 0.019 |
| plate.mid-down | throat piezo mid-down.3 | PZT-8, silvered | resolved | 2.5 | 0.019 |
| plate.mid-down | rim electronics mid-down | FR4 + electronics | derived | 236.4 | 0.437 |
| plate.deck | face plate deck | Al 6082, dark machined | committed | 1148.3 | 3.100 |
| plate.deck | carrier ring deck | Al 6063, champagne anodized | resolved | 341.1 | 0.921 |
| plate.deck | gyroid horn deck | Graded ceramic gyroid (alumina, ρ_rel 0.25) | committed | 321.3 | 0.317 |
| plate.deck | inner cone deck | Copper | committed | 2.9 | 0.026 |
| plate.deck | throat piezo deck.1 | PZT-8, silvered | resolved | 2.5 | 0.019 |
| plate.deck | throat piezo deck.2 | PZT-8, silvered | resolved | 2.5 | 0.019 |
| plate.deck | throat piezo deck.3 | PZT-8, silvered | resolved | 2.5 | 0.019 |
| plate.deck | rim electronics deck | FR4 + electronics | derived | 236.4 | 0.437 |
| torus.top | torus former top | Torus former, glass-filled PEEK | committed | 487.8 | 0.732 |
| torus.top | winding top CW (feed A) | Copper | assumed | 114.0 | 1.021 |
| torus.top | winding top CCW (feed B) | Phosphor bronze | assumed | 132.8 | 1.168 |
| torus.middle | torus former middle | Torus former, glass-filled PEEK | committed | 487.8 | 0.732 |
| torus.middle | winding middle CW (feed A) | Copper | assumed | 114.0 | 1.021 |
| torus.middle | winding middle CCW (feed B) | Phosphor bronze | assumed | 132.8 | 1.168 |
| torus.deck | torus former deck | Torus former, glass-filled PEEK | committed | 487.8 | 0.732 |
| torus.deck | winding deck CW (feed A) | Copper | assumed | 114.0 | 1.021 |
| torus.deck | winding deck CCW (feed B) | Phosphor bronze | assumed | 132.8 | 1.168 |
| bore | bore collar top | Al 6082, dark machined | resolved | 3.5 | 0.009 |
| bore | bore collar middle | Al 6082, dark machined | resolved | 5.1 | 0.014 |
| bore | bore feed tube deck | Al 6082, dark machined | resolved | 4.9 | 0.013 |
| enclosure | rear glass (fixed) | Low-iron laminated glass, ITO-class coat | committed | 1271.3 | 3.178 |
| enclosure | front glass (rotating) | Low-iron laminated glass, ITO-class coat | committed | 1306.0 | 3.265 |
| enclosure | front glass lower end-band | Al 6063, champagne anodized | derived | 14.1 | 0.038 |
| enclosure | front glass upper end-band | Al 6063, champagne anodized | derived | 14.1 | 0.038 |
| enclosure | V-groove track lower | Al 6063, champagne anodized | derived | 9.9 | 0.027 |
| enclosure | V-groove track upper | Al 6063, champagne anodized | derived | 9.9 | 0.027 |
| enclosure | V-roller lower 1 | POM | assumed | 0.1 | 0.000 |
| enclosure | V-roller lower 2 | POM | assumed | 0.1 | 0.000 |
| enclosure | V-roller lower 3 | POM | assumed | 0.1 | 0.000 |
| enclosure | V-roller upper 1 | POM | assumed | 0.1 | 0.000 |
| enclosure | V-roller upper 2 | POM | assumed | 0.1 | 0.000 |
| enclosure | V-roller upper 3 | POM | assumed | 0.1 | 0.000 |
| arcade | arcade column 1 | Al 6063, dark anodized | resolved | 82.8 | 0.224 |
| arcade | RX / status strip 1 | LED strip | derived | 2.4 | 0.004 |
| arcade | arcade column 2 | Al 6063, dark anodized | resolved | 82.8 | 0.224 |
| arcade | RX / status strip 2 | LED strip | derived | 2.4 | 0.004 |
| arcade | arcade column 3 | Al 6063, dark anodized | resolved | 82.8 | 0.224 |
| arcade | RX / status strip 3 | LED strip | derived | 2.4 | 0.004 |
| arcade | arcade column 4 | Al 6063, dark anodized | resolved | 82.8 | 0.224 |
| arcade | RX / status strip 4 | LED strip | derived | 2.4 | 0.004 |
| arcade | arcade column 5 | Al 6063, dark anodized | resolved | 82.8 | 0.224 |
| arcade | RX / status strip 5 | LED strip | derived | 2.4 | 0.004 |
| arcade | arcade column 6 | Al 6063, dark anodized | resolved | 82.8 | 0.224 |
| arcade | RX / status strip 6 | LED strip | derived | 2.4 | 0.004 |
| arcade | arcade column 7 | Al 6063, dark anodized | resolved | 82.8 | 0.224 |
| arcade | RX / status strip 7 | LED strip | derived | 2.4 | 0.004 |
| photonic | photonic bay tile 1 | Laminated glass tile, metal-mesh hologram | site | 226.0 | 0.565 |
| photonic | photonic bay tile 2 | Laminated glass tile, metal-mesh hologram | site | 226.0 | 0.565 |
| photonic | photonic bay tile 3 | Laminated glass tile, metal-mesh hologram | site | 226.0 | 0.565 |
| photonic | photonic bay tile 4 | Laminated glass tile, metal-mesh hologram | site | 226.0 | 0.565 |
| photonic | photonic bay tile 5 | Laminated glass tile, metal-mesh hologram | site | 226.0 | 0.565 |
| photonic | photonic bay tile 6 | Laminated glass tile, metal-mesh hologram | site | 226.0 | 0.565 |
| body | LED status ring | LED strip | derived | 25.3 | 0.047 |
| base | air intake filter | Envelope only (not specified) | assumed | 1278.3 | — |
| base | water reservoir | Envelope only (not specified) | assumed | 2376.0 | — |
| base | graphite block bay | Envelope only (not specified) | assumed | 1200.0 | — |
| base | power supply | Envelope only (not specified) | assumed | 945.0 | — |
| base | compute + router | Envelope only (not specified) | assumed | 560.0 | — |
| base | feed pump | Envelope only (not specified) | assumed | 136.6 | — |
| base | cartridge circle | Envelope only (not specified) | assumed | 1968.8 | — |
| crown | optical stem head | Envelope only (not specified) | assumed | 84.6 | — |
| crown | touch UI 7in | Envelope only (not specified) | resolved | 27.1 | — |

**Total (excluding placeholder envelopes): 68.78 kg**

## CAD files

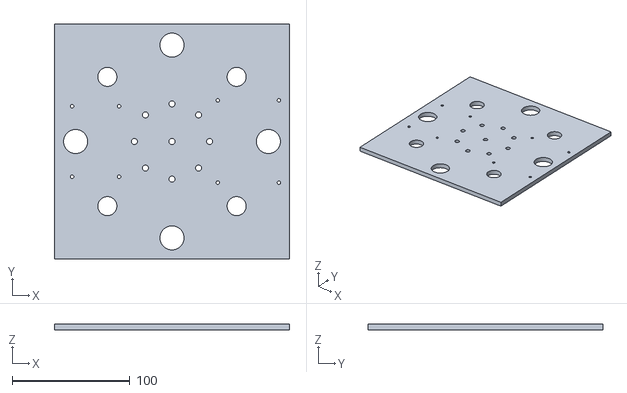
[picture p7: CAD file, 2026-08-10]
cad/lpoh_plate_v1.stl
200.0 x 200.0 x 5.00

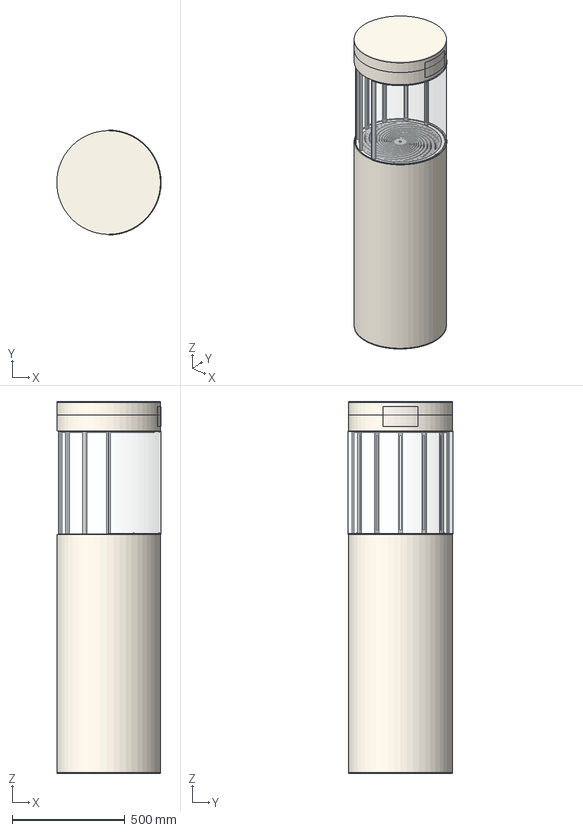
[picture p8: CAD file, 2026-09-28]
cad/rh1-freestanding/rh1.step
462.6 x 466.0 x 1650.0 mm
body__bottom_closure_part
body__lower_body_tube_part
body__top_band_part
body__crown_part
body__crown_cap_part
storage__storage_chamber_liner_part
plate.top__face_plate_top_part x 4
plate.top__carrier_ring_top_part
plate.top__gyroid_horn_top_part
plate.top__inner_cone_top_part
plate.top__throat_piezo_top.1_part x 12
plate.top__rim_electronics_top_part
plate.mid-up__carrier_ring_mid-up_part
plate.mid-up__gyroid_horn_mid-up_part
plate.mid-up__inner_cone_mid-up_part
plate.mid-up__rim_electronics_mid-up_part
plate.mid-down__carrier_ring_mid-down_part
plate.mid-down__gyroid_horn_mid-down_part
plate.mid-down__inner_cone_mid-down_part
plate.mid-down__rim_electronics_mid-down_part
plate.deck__carrier_ring_deck_part
plate.deck__gyroid_horn_deck_part
plate.deck__inner_cone_deck_part
plate.deck__rim_electronics_deck_part
torus.top__torus_former_top_part x 3
torus.top__winding_top_CW_(feed_A)_part x 3
torus.top__winding_top_CCW_(feed_B)_part x 3
bore__bore_collar_top_part
bore__bore_collar_middle_part
bore__bore_feed_tube_deck_part
enclosure__rear_glass_(fixed)_part
enclosure__front_glass_(rotating)_part
enclosure__front_glass_lower_end-band_part
enclosure__front_glass_upper_end-band_part
enclosure__V-groove_track_lower_part
enclosure__V-groove_track_upper_part
enclosure__V-roller_lower_1_part
enclosure__V-roller_lower_2_part
enclosure__V-roller_lower_3_part
enclosure__V-roller_upper_1_part
enclosure__V-roller_upper_2_part
enclosure__V-roller_upper_3_part
arcade__arcade_column_1_part
arcade__RX____status_strip_1_part
arcade__arcade_column_2_part
arcade__RX____status_strip_2_part
arcade__arcade_column_3_part
arcade__RX____status_strip_3_part
arcade__arcade_column_4_part
arcade__RX____status_strip_4_part
arcade__arcade_column_5_part
arcade__RX____status_strip_5_part
arcade__arcade_column_6_part
arcade__RX____status_strip_6_part
arcade__arcade_column_7_part
arcade__RX____status_strip_7_part
photonic__photonic_bay_tile_1_part
photonic__photonic_bay_tile_2_part
photonic__photonic_bay_tile_3_part
photonic__photonic_bay_tile_4_part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

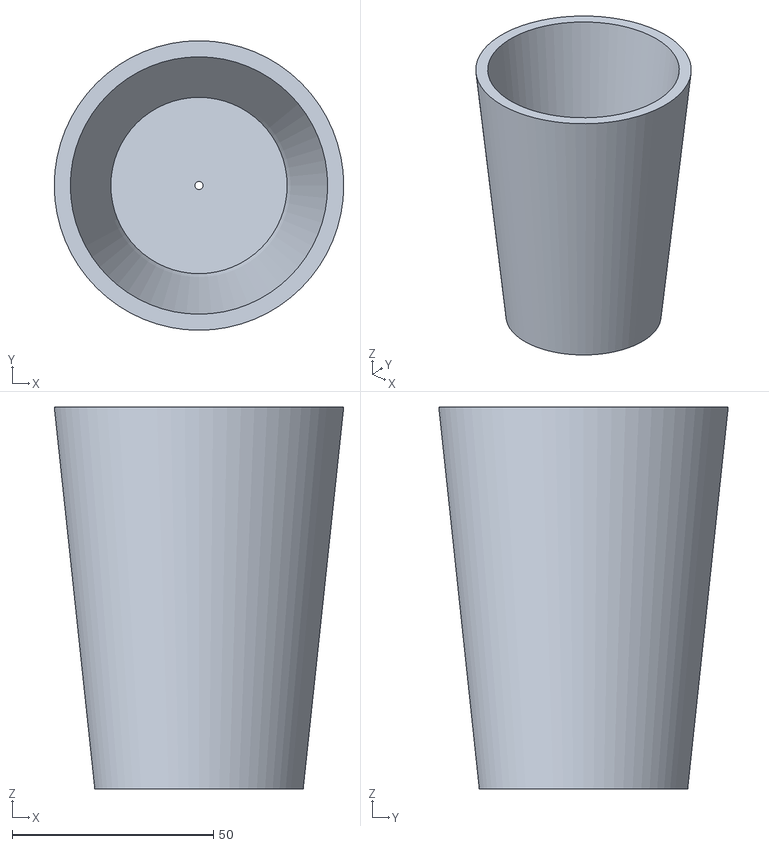
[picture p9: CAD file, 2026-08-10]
twin/Samples/cup.stl
72.0 x 72.0 x 95.0

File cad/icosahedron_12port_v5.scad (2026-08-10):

// icosahedron_12port_v5.scad
// ------------------------------------------------------------------
// v5 — simplified first prototype for 3 mm pre-wired LEDs.
//
// Solid SLA icosahedron. 12 bores at vertices with:
//   - external cylindrical collar (2 mm tall, 6 mm OD) for glue joint
//   - 3.2 mm bore (0.2 mm clearance for 3 mm LED + glue)
//   - 4.5 mm cylindrical depth for LED body
//   - hemispheric seat at the bore tip for the LED's dome
//
// Assembly:
//   LEDs inserted tip-first from OUTSIDE the body. Dome seats into the
//   hemispheric cap at the bore's inner end. Wires stick out through
//   the collar. Dab of UV resin in the bore before insertion bonds
//   everything when cured.
//
// Physics unchanged from v3: solid SLA body IS the optical medium.
// Photons propagate from one LED dome through the bulk to other LED
// domes. Just smaller LEDs, cleaner vertex ports.
// ------------------------------------------------------------------

// ---- PARAMETERS ----
circumradius       = 20;    // center → outer vertex (mm)
socket_diameter    = 3.2;   // 3 mm LED + 0.2 mm glue clearance
socket_depth       = 3.0;   // cylindrical portion of bore (until hemisphere)
dome_radius        = 1.6;   // hemispheric seat for LED dome (≈ socket/2)
collar_od          = 6.0;   // external collar outer diameter
collar_height      = 2.0;   // how far collar protrudes past outer face
collar_embed       = 9.0;   // how far collar cylinder extends INWARD to merge
                            // cleanly with the icosahedron's faces (instead
                            // of floating on the pointy vertex).
fn_global          = 48;    // curves; bump to 96 for final if needed
// --------------------

$fn = fn_global;

// --- Icosahedron geometry (same math as v3 / v4) ---
phi            = (1 + sqrt(5)) / 2;
icos_raw_norm  = sqrt(1 + phi * phi);
icos_scale     = circumradius / icos_raw_norm;

icos_vertices_raw = [
    [0,  1,  phi], [0,  1, -phi], [0, -1,  phi], [0, -1, -phi],
    [ 1,  phi, 0], [ 1, -phi, 0], [-1,  phi, 0], [-1, -phi, 0],
    [ phi, 0,  1], [ phi, 0, -1], [-phi, 0,  1], [-phi, 0, -1],
];

// Orient so one FACE points down (stable base, all 12 vertices pointy).
face_center_raw  = [(0 + phi + 1) / 3, (-1 + 0 - phi) / 3, (-phi - 1 + 0) / 3];
face_center_unit = face_center_raw / norm(face_center_raw);
rot_axis         = cross(face_center_unit, [0, 0, -1]);
rot_axis_norm    = norm(rot_axis);
rot_angle        = acos(face_center_unit * [0, 0, -1]);

function apply_rotation(p) =
    rot_axis_norm < 1e-6 ? p :
    (let (k = rot_axis / rot_axis_norm, c = cos(rot_angle), s = sin(rot_angle))
     p * c + cross(k, p) * s + k * (k * p) * (1 - c));

icos_unit  = [ for (v = icos_vertices_raw) apply_rotation(v) / icos_raw_norm ];
icos_outer = [ for (u = icos_unit) u * circumradius ];

icos_faces = [
    [0, 2, 8], [0, 8, 4], [0, 4, 6], [0, 6, 10], [0, 10, 2],
    [3, 9, 5], [3, 5, 7], [3, 7, 11], [3, 11, 1], [3, 1, 9],
    [8, 2, 5], [8, 5, 9], [8, 9, 4], [4, 9, 1], [4, 1, 6],
    [6, 1, 11], [6, 11, 10], [10, 11, 7], [10, 7, 2], [2, 7, 5],
];

module solid_icosahedron() {
    polyhedron(points = icos_outer, faces = icos_faces, convexity = 4);
}

// ---- Per-vertex feature helpers ----

// Apply the rotation that takes local +Z to the outward radial direction
// at a vertex u, then run children() in that frame.
module at_vertex(u) {
    outward   = u;
    axis      = cross([0, 0, 1], outward);
    axis_norm = norm(axis);
    ang       = acos(outward[2]);
    translate(outward * circumradius) {
        if (axis_norm > 1e-6)       rotate(a = ang, v = axis) children();
        else if (outward[2] > 0)                              children();
        else                         rotate([180, 0, 0])      children();
    }
}

// External collar: a raised ring around each vertex's bore.
// In local frame, +z is outward, z = 0 is the outer vertex point. The
// cylinder extends INWARD by collar_embed (so it merges cleanly with
// the triangular faces meeting at the vertex) and OUTWARD by
// collar_height (the visible raised lip).
module collar(u) {
    at_vertex(u) {
        translate([0, 0, -collar_embed])
            cylinder(h = collar_embed + collar_height, d = collar_od);
    }
}

// Bore + hemispheric dome seat, subtracted through the collar and body.
module bore_with_dome(u) {
    at_vertex(u) {
        // Clear out the collar + body to depth socket_depth from the
        // outer face. Local z goes from z = collar_height (top of collar)
        // DOWN to z = -socket_depth (inside the body).
        translate([0, 0, -socket_depth])
            cylinder(h = socket_depth + collar_height + 0.5,
                     d = socket_diameter);

        // Hemispheric seat: half-sphere at z = -socket_depth, dome
        // opening further negative z (inward). LED's 3 mm dome seats
        // into this 1.6 mm-radius cup with ~0.1 mm glue clearance.
        translate([0, 0, -socket_depth])
            sphere(r = dome_radius);
    }
}

// ---- Assembled part ----
module icosahedron_12port() {
    difference() {
        union() {
            solid_icosahedron();
            for (u = icos_unit) collar(u);
        }
        for (u = icos_unit) bore_with_dome(u);
    }
}

icosahedron_12port();

// ---- Informational echos ----
echo("circumradius (to vertex)  =", circumradius, "mm");
echo("outer edge length         =", 2 * icos_scale, "mm (LED-to-LED spacing)");
echo("socket bore               =", socket_diameter, "mm × depth", socket_depth, "mm");
echo("dome seat radius          =", dome_radius, "mm");
echo("collar                    = OD", collar_od, "mm, height", collar_height, "mm");
echo("LED tip depth from vertex =", socket_depth + dome_radius, "mm");
echo("LED tip distance from center =", circumradius - socket_depth - dome_radius, "mm");
echo("A5 irrep decomposition on 12 vertices: 1 + 3 + 3' + 5");

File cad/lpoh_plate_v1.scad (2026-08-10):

// lpoh_plate_v1.scad
// ------------------------------------------------------------------
// Last Piece Of Hardware — Phase 1 plate.
//
// 200 × 200 × 5 mm acrylic/PLA plate. Three-machines-in-one host:
//   - acoustic hologram  (4 × 40 kHz tweeters, phased)
//   - optical compute     (4 × 5 mm RGB LED + 4 × 5 mm photodiode)
//   - 3D printer mode     (UV 365 nm LED bores up through the centre)
//
// Mount holes for a Waveshare RP2350B + 2.8" LCD module off to one side.
// Edge slots for 4 × 16 mm piezo transducers acting as large-area RX.
//
// Generated as a single flat part. Rendered to STL, then printed
// face-down on FDM. Drill slightly if fits are tight.
// ------------------------------------------------------------------

// ---- PARAMETERS ----
plate_x          = 200;
plate_y          = 200;
plate_z          = 5;

// Acoustic hologram: 4 tweeters in a square, symmetric about centre.
tweeter_od       = 16.2;    // 16 mm tweeter + 0.2 mm clearance
tweeter_pitch    = 110;     // centre-to-centre, opposing tweeters aim
                            // at each other across 110 mm

// Piezo RX disks: 4 × 16 mm, mounted on the edges (between tweeters).
piezo_od         = 20.5;    // 20 mm piezo disc + 0.5 mm clearance
piezo_edge_off   = 18;      // centre of piezo, from plate edge

// Optical IO: 4 × 5 mm RGB LED + 4 × 5 mm photodiode. Interleaved
// around the inner ring so each LED faces a PD across the chamber.
opt_ring_radius  = 32;      // radius of optical IO ring, mm
opt_led_od       = 5.2;     // 5 mm LED + 0.2 mm clearance
opt_pd_od        = 5.2;
opt_count        = 8;       // 4 LED + 4 PD alternating

// UV printer LED (centre): points UP through a small hole, lights
// the levitation volume for resin cure.
uv_od            = 5.2;

// Waveshare RP2350B + 2.8" LCD mounting: 4 × M2.5 standoffs in a
// 52 × 70 rectangle (verify against your exact board silkscreen).
lcd_origin       = [65, 0];
lcd_rect         = [52, 70];
standoff_od      = 3.0;     // through-hole for M2.5

// Perf-board scratch pad off to the opposite side.
perf_origin      = [-65, 0];
perf_rect        = [40, 60];
perf_standoff    = 3.0;

// General cosmetics
fn_global        = 64;
label_depth      = 0.6;     // engraved text depth
// --------------------

$fn = fn_global;

module plate_blank() {
    translate([0, 0, -plate_z / 2])
        cube([plate_x, plate_y, plate_z], center = false)
        ;
}

// --- Acoustic tweeters: 4 in a square at ±pitch/2 ---
tweeter_pos = [
    [plate_x/2 - tweeter_pitch/2, plate_y/2 - tweeter_pitch/2],
    [plate_x/2 + tweeter_pitch/2, plate_y/2 - tweeter_pitch/2],
    [plate_x/2 + tweeter_pitch/2, plate_y/2 + tweeter_pitch/2],
    [plate_x/2 - tweeter_pitch/2, plate_y/2 + tweeter_pitch/2],
];

module tweeter_holes() {
    for (p = tweeter_pos)
        translate([p[0], p[1], -plate_z])
            cylinder(h = plate_z * 3, d = tweeter_od);
}

// --- Piezo RX discs: 4 edge-centered between tweeters ---
piezo_pos = [
    [plate_x/2, piezo_edge_off],             // south edge
    [plate_x - piezo_edge_off, plate_y/2],   // east  edge
    [plate_x/2, plate_y - piezo_edge_off],   // north edge
    [piezo_edge_off, plate_y/2],             // west  edge
];

module piezo_holes() {
    for (p = piezo_pos)
        translate([p[0], p[1], -plate_z])
            cylinder(h = plate_z * 3, d = piezo_od);
}

// --- Optical ring: 8 holes alternating LED / PD around centre ---
module optical_ring() {
    for (i = [0 : opt_count - 1]) {
        ang = 360 * i / opt_count;
        x = plate_x/2 + opt_ring_radius * cos(ang);
        y = plate_y/2 + opt_ring_radius * sin(ang);
        d = (i % 2 == 0) ? opt_led_od : opt_pd_od;
        translate([x, y, -plate_z])
            cylinder(h = plate_z * 3, d = d);
    }
}

// --- UV LED: single 5 mm hole in the dead centre ---
module uv_hole() {
    translate([plate_x/2, plate_y/2, -plate_z])
        cylinder(h = plate_z * 3, d = uv_od);
}

// --- Board mounting standoffs ---
module rect_standoffs(origin_xy, rect_wh, d) {
    cx = plate_x/2 + origin_xy[0];
    cy = plate_y/2 + origin_xy[1];
    w  = rect_wh[0];
    h  = rect_wh[1];
    for (dx = [-w/2, w/2], dy = [-h/2, h/2])
        translate([cx + dx, cy + dy, -plate_z])
            cylinder(h = plate_z * 3, d = d);
}

module lcd_standoffs() { rect_standoffs(lcd_origin,  lcd_rect,  standoff_od); }
module perf_standoffs() { rect_standoffs(perf_origin, perf_rect, perf_standoff); }

// --- Engraved labels (cosmetic, shallow) ---
module label_at(xy, text_str, sz) {
    translate([xy[0], xy[1], -label_depth])
        linear_extrude(height = label_depth + 0.01)
            text(text_str, size = sz, halign = "center",
                 valign = "center", font = "Helvetica");
}

module labels() {
    // Corner labels near each tweeter
    for (i = [0 : 3]) {
        p = tweeter_pos[i];
        ang = 360 * i / 4 + 45;
        off = 15;
        translate([p[0] + off * cos(ang), p[1] + off * sin(ang), 0])
            label_at([0, 0], str("T", i + 1), 4);
    }
    // Edge piezo labels
    piezo_tags = ["P1", "P2", "P3", "P4"];
    for (i = [0 : 3])
        translate([piezo_pos[i][0], piezo_pos[i][1] +
                   (i == 0 ? 14 : i == 2 ? -14 : 0), 0]) {
            // offset text off-axis so it isn't under the piezo
            if (i == 1) translate([-14, 0, 0]) label_at([0, 0], piezo_tags[i], 4);
            else if (i == 3) translate([14, 0, 0]) label_at([0, 0], piezo_tags[i], 4);
            else label_at([0, 0], piezo_tags[i], 4);
        }
    // Centre label
    translate([plate_x/2, plate_y/2 - 10, 0])
        label_at([0, 0], "UV", 3);
}

// --- Assembled plate ---
module lpoh_plate() {
    difference() {
        plate_blank();
        tweeter_holes();
        piezo_holes();
        optical_ring();
        uv_hole();
        lcd_standoffs();
        perf_standoffs();
        labels();
    }
}

lpoh_plate();

// ---- Informational echos ----
echo("plate                =", plate_x, "x", plate_y, "x", plate_z, "mm");
echo("tweeter pitch        =", tweeter_pitch, "mm (opposing pair baseline)");
echo("tweeter OD           =", tweeter_od, "mm");
echo("piezo OD             =", piezo_od, "mm");
echo("optical ring radius  =", opt_ring_radius, "mm");
echo("optical holes        =", opt_count, "(4 LED + 4 PD alternating)");
echo("UV centre hole OD    =", uv_od, "mm");
echo("LCD standoffs rect   =", lcd_rect, "mm (M2.5)");
echo("perf standoffs rect  =", perf_rect, "mm (M2.5)");

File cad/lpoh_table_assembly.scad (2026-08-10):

// ══════════════════════════════════════════════════════════════════
// LPOH Table Assembly — The Last Piece of Hardware
// ══════════════════════════════════════════════════════════════════
// 6+6 ultrasonic transducers in hex ring layout,
// top plate rotated 30° for acoustic path diversity.

// ── Parameters ─────────────────────────────────────────────────
transducer_od     = 16;
transducer_height = 12;
hole_clearance    = 0.5;
hole_dia          = transducer_od + hole_clearance;

pin_dia           = 0.6;
pin_length        = 5;
pin_spacing       = 10;

plate_thickness   = 3;
ring_radius       = 26;
edge_margin       = 4;
plate_radius      = ring_radius + hole_dia/2 + edge_margin;
corner_radius     = 5;

gap               = 50;
top_rotation      = 30;

// (plate shape is a circle now)

// ── Transducer ─────────────────────────────────────────────────
module transducer(pins_up = true) {
    color("DimGray")
    cylinder(h = transducer_height, d = transducer_od, $fn = 32);

    // Two pin legs
    pin_z = pins_up ? transducer_height : -pin_length;
    color("Gold")
    for (dx = [-pin_spacing/2, pin_spacing/2]) {
        translate([dx, 0, pin_z])
        cylinder(h = pin_length, d = pin_dia, $fn = 8);
    }
}

// ── Ring positions (6 transducers, no center) ──────────────────
function ring_positions(r, offset_deg = 0) =
    [for (k = [0:5])
        [r * cos(offset_deg + k * 60),
         r * sin(offset_deg + k * 60)]
    ];

// ── Array plate (hex aligned with transducer ring) ─────────────
module array_plate(ring_offset_deg = 0) {
    positions = ring_positions(ring_radius, ring_offset_deg);

    difference() {
        // Circular plate
        color("SteelBlue", 0.7)
        cylinder(h = plate_thickness, r = plate_radius, $fn = 64);

        // Transducer holes
        for (p = positions) {
            translate([p[0], p[1], -0.1])
            cylinder(h = plate_thickness + 0.2, d = hole_dia, $fn = 32);
        }
    }
}

// ══════════════════════════════════════════════════════════════════
// ASSEMBLY
// ══════════════════════════════════════════════════════════════════

// ── Bottom plate ───────────────────────────────────────────────
array_plate(0);

// ── Bottom transducers (pins down) ─────────────────────────────
for (p = ring_positions(ring_radius, 0)) {
    translate([p[0], p[1], plate_thickness - transducer_height])
    transducer(pins_up = false);
}

// ── Top plate ──────────────────────────────────────────────────
translate([0, 0, plate_thickness + gap])
array_plate(top_rotation);

// ── Top transducers (pins up) ──────────────────────────────────
for (p = ring_positions(ring_radius, top_rotation)) {
    translate([p[0], p[1], plate_thickness + gap + plate_thickness])
    transducer(pins_up = true);
}

// ── Build volume indicator ─────────────────────────────────────
%translate([0, 0, plate_thickness + 8])
color("Yellow", 0.05)
cylinder(h = gap - 16, r = ring_radius - 5, $fn = 32);

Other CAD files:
cad/rh1-freestanding/rh1_freestanding_rev3.blend
cad/rh1_freestanding_rev2.blend

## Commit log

2026-08-10 Initial public release: RSW-1 digital twin, RH-1 CAD, research papers
    The field compiler (Swift + Metal digital twin of the RH-1 machine), the
    RH-1 and bench-chamber CAD sources, the research corpus, and the
    pre-registered quasicrystal array study.
    [cup.stl, icosahedron_12port_v5.scad, lpoh_plate_v1.scad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]
2026-09-28 twin: RH-1 free-standing CAD inside the twin; plate-primary preset; propagator fixes
    The free-standing RH-1 as a parametric solid model in FieldCore, with no
    dependencies: 92 parts built from etherworks.io (2026-08-10), mech §3c and
    spec v0.4, every number carrying its provenance, and nine conflicts between
    those sources resolved in code (twin/CAD.md). CAD gates (watertight solids,
    closed-form volumes, 25 design rules, interference, dimension audit,
    parastichies, horn arc), a Metal solid renderer with hatched section caps, a
    Machine tab in the app, and exports: STL / OBJ / BOM / parameters, a
    general-arrangement drawing, B-rep STEP via CadQuery with a cross-kernel
    volume gate, and a rev3 Bl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
    [rh1.step, rh1_freestanding_rev3.blend]
2026-09-28 twin: receipts for the CAD gates, physics gates and plate study at f61c82d
    Generated from the committed tree (clean SHA): 9/9 CAD gates, 11/11
    physics gates, and the plate-aperture study the README quotes.
2026-09-29 twin: draw the live viewport on demand; stop per-part vertex reallocation
    The live Metal view ran MTKView's continuous 60 Hz loop and redrew an
    unchanged frame forever: ~60% GPU, ~3% CPU and ~114 wakeups/s with the
    app idle. It now draws only when something visible changes (camera,
    scene, mode, section, overlays, resize).
    SolidGeometry.append reserved exact capacity before every part, so
    building the Machine tab re-copied its vertex buffer once per part (92
    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
2026-09-29 twin: temperature-aware air, GPU port fields, free-standing machine everywhere, drift study
    - Medium.air(temperatureC:humidity:pressure:): sound speed and density from
    a dry-air / water-vapour ideal-gas mixture, absorption from ISO 9613-1
    (4.66 dB/km at 1 kHz; 1.32 / 3.28 / 8.23 dB/m at 40 / 100 / 200 kHz, room
    air). Absorption acts on every propagator path, wall images included; the
    horn channels hold the same air (c/sqrt(tortuosity)). The fixed §12 media
    are unchanged, so every earlier receipt replays.
    - PortFieldsGPU + the buildPortFields kernel: the gate-granular operator for
    any preset (horn couplings, wall images, absorption), handed to the CPU
    pipeline as Propagator(pre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
2026-09-29 twin: screenshot fixtures describe the free-standing machine
    The scene registry's inspector rows still carried the desktop preset
    (24 gates, Ø280 × 300, 20–80 kHz). They now match what the live app reads
    from RH1Freestanding.standard() at launch.
2026-09-29 twin: receipts at 7b53f44 (drift, GPU, physics gates) and screenshots of the free-standing machine
    - drift: G-T1 passes (direct-path node drift = d·Δc/c); walls rows informational
    - gpu: G-GPU 3.8e-6; G-GPU-FS 1.3e-5 (40 kHz), 5.3e-5 (100 kHz)
    - gates: all 11 physics gates pass
    - shots: 22 scenes + contact sheets, and the machine / overlay renders,
    regenerated with the free-standing chamber
2026-09-29 twin: force compiler (Gor'kov as a quadratic form), exact gradient rows, forcetrap study
    - Propagator.gateGradientRows and a buildPortFieldsGrad GPU kernel: per-gate
    pressure rows with their analytic gradients (G-GPU-FS-grad 1.4e-5). Both
    gradients (and velocity()) now carry the piston directivity's angular
    slope, dD/dcos = 2 J2(x) cos/sin^2 (new besselJ0); the old "locally
    constant" shortcut missed 1-2 % of the lateral gradient at ka ~ 1.8, and
    the rows now match finite differences to 1e-8.
    - ForceCompiler: U(x) = g^H K(x) g per tone (checked against
    Gorkov.potential to 1e-9); well depth (shell mean - centre) is a quadratic
    form too. Maximise the target's depth, penalise every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
2026-09-29 twin: cylindrical-cavity field model (the glass side wall), validated against Rayleigh
    The plate-image model reflects off the two plates only; the glass is a
    near-perfect mirror too (69-83 dB transmission loss at 40-200 kHz). For a
    cylinder the exact field has a closed modal form: J_m(gamma r) e^{im phi}
    across the chamber (every order of glass reflection), and the plate-to-plate
    reflections summed in closed form along the axis. About 1e4 mode
    coefficients per gate at 40 kHz.
    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
2026-09-29 twin: cavity model on the GPU and in Propagator; drift study with the glass
    - buildCavityFields kernel + CavityFieldsGPU: the modal sum per point and
    gate (optionally with gradients), the float Bessel table cached per
    cavity. G-GPU-CYL: 8.3e-6 against the CPU rows (8 960 modes, 40 kHz).
    - Propagator(cavity:cavitySource:): every evaluator (H, gateRow,
    gateGradientRows, pressure, velocity) uses the cavity's modal sum, so the
    inverse solver, force compiler and drift study run on the glass chamber.
    - RH1Freestanding.chamber(maxGamma:): the build chamber as a cylinder of
    the rear glass's inner radius (218 mm), faces 460 mm apart, R = 0.9,
    cached per mode range.
    - ThermalDrift takes fi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
2026-09-29 twin: forcetrap --glass (force compiler in the glass cavity)
    With the glass as a mirror (cavity model, R = 0.9 plates), neither GS-PAT
    nor the force compiler holds a unique trap: one tone reaches sibling ratio
    1.4-1.5, the 5-tone chord 1.23 at the mid-plane with 253 wells above half
    depth within +-17 mm, 0.93 near the lower face. The plate-only model
    overstated trap quality; a diffuse chamber's speckle outnumbers 6 drives.
2026-09-29 Twin: fix the plate image series for wall-mounted sources; glass wall admittance + wallsweep
    The image model placed a source that sits ON a plate between the walls and
    then added that plate's own image at the source point (weight R) — but a
    plate-mounted aperture is already baffled by the Rayleigh half-space
    prefactor, so every later image was duplicated and the field inflated by
    (1 + R): 1.9x at R = 0.9. The cylindrical-cavity model caught it. Sources on
    a wall now bounce alternately off the far wall and the near one.
    - G-CYL3: plate-mounted point sources, image series (16 orders) vs the
    cavity's closed-form plate series with the side wall silenced by loss:
    agree to 1.1e-5 (the doubl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
2026-09-29 Twin: exact lined glass wall (complex radial modes); GPU plate images match the CPU fix
    The glass side wall can now be lined: specific admittance beta, wall
    condition dp/dr = i k beta p, solved EXACTLY. Each mode's zero is continued
    from its rigid j'_mn to the root of x J'_m(x) = i (k a beta) J_m(x) (Euler
    predictor + Newton), and J_m at the complex argument is read off the same
    real Miller table by the multiplication theorem (DLMF 10.23.1) — on the CPU
    and in the Metal kernel. Low modes graze the wall and turn pressure-release-
    like with little loss; head-on modes are the ones a liner kills. The first-
    order perturbation it replaces fails once k a beta >~ j' (beta ~ 0.05 at
    40 kHz already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
2026-09-29 Twin receipts at cce6bf5: gates, gpu, forcetrap (plates, glass), wallsweep (glass, plates grids), drift
    - gates: all 11 pass. gpu: all 6 pass (G-GPU-FS 1.35e-5 after the kernel
    image fix; G-GPU-CYL 8.3e-6; G-GPU-CYL-lined 8.5e-6).
    - forcetrap, plates only: G-F1 passes, 5-tone chord sibling ratio 0.39, no
    competing well above half depth.
    - forcetrap --glass: bare glass breaks it — one tone 1.41, chord 1.23 with
    253 siblings; near the lower face 0.93.
    - wallsweep: an exact locally-reacting liner does not restore a unique trap
    (chord 1.43-3.09 for liner R 0.3-0.9; 0.97 at R = 0; everything absorbing
    0.77 with 8 siblings).
    - drift: G-T1 passes; bare glass decorrelates a held trap by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
2026-09-29 Twin: force compiler ~12x faster — no per-point heap arrays, parallel well finding
    - ForceCompiler.potential: chunked, local accumulators instead of a heap
    array per probe point (it runs every step of every refinement).
    - ForceCompiler.wells: inline neighbour tests, parallel over z-slices.
    - Options.perToneStarts / perToneIterations (100): the per-tone pre-pass of
    a chord is shorter, and warm re-compiles (forcetrap's thermal loop) skip it.
    A 5-tone glass-chamber compile: 12.5 s, was ~150 s; same result (0.70).
    58 tests pass.
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2026-09-29 Twin round 8: a bead that moves — fly receipt, trajectory, chart, README
    - Receipts/fly_*.json at 6f284f8 (G-P2 PASS) and the 4x / 40 ms trajectory.
    - Tools/plot_fly.py (standard library only) -> shots/fly_4x_40ms.svg: the
    bead against the stepped target well, height and sideways.
    - README: `fieldc fly` in Round 8 and the command list.
    [fly_trajectory_4x_40ms.csv]
2026-09-30 Twin: the first build — five beads laid in a row (`fieldc build`, G-B1); compile the force balance
    - ForceCompiler.moveWell / carryStep take `balance`: the external force per
    unit drive power the trap must hold at x, so the condition is
    grad U(x) = balance (gravity: (0, 0, -mg/P)). The bead then RESTS on its
    aim; compiled as a potential minimum it hung 0.2 mm below and 0.5 mm aside
    (the well is soft sideways and its axes tilt).
    - fieldc build [--beads N] [--debug]: each PLA bead is loaded into the
    force-balanced pick-up trap, carried (ramped 40 ms steps, 4x holding
    drive) to hover 0.15 mm above its site, and lowered in 0.05 mm steps with
    closed-loop correction (the twin reads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
2026-09-30 Twin round 9: the first build — receipt at fd0b816, figure, README
    G-B1 PASS: five PLA beads in a row on the support, 2-3.5 um from their
    sites, neighbours 7-9 um apart, straight to +-2 um, 8.5 s simulated; placed
    beads pushed by up to 4.5x their weight by later traps.
    shots/build_row.svg (Tools/plot_build.py): side view with every bead's path,
    top view of the row.
    [build_placed.csv, build_trajectories.csv]
2026-09-30 Twin round 9: the tetrahedron — receipts at 6da260d, figure, README
    G-B2 PASS (a fourth bead resting on three, gaps 1.7/0.0/3.3 um) and the row
    re-run at the same SHA (G-B1 PASS). shots/build_tetra.svg; plot_build.py
    fits the top view to the build.
    [build_tetra_placed.csv, build_tetra_trajectories.csv]
2026-09-30 Twin: part growth — placed beads scatter, and the build compiles through the part's field
    - Scatterers: each placed bead scatters as a monopole (f1) plus a dipole (f2),
    driven by the LOCAL field (chamber + every other bead) — coupled dipoles,
    solved per gate — and adds per-gate rows, so the compiler, the carry and the
    force balance see the part. G-S1: vs the exact rigid-sphere series at
    ka = 0.1, 1.3 %. G-S2: two beads in an oscillating flow vs the Koenig
    interaction energy -(pi/2) f2^2 rho a^6 v^2 (1 - 3cos^2)/R^3, 1.0 %
    (attraction side by side, repulsion end to end).
    - build: after each placement the part's field joins the fine box, and a
    25 um grid around the part res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
2026-09-30 Twin round 10: part growth — receipts at 4974f42, figures, README
    G-B1 (row) and G-B2 (tetrahedron, base along y) PASS with the part scattering.
    README "Round 10": the part in the field, what it does to a build, what is
    open, and the turn to scan-and-mold.
    [build_placed.csv, build_tetra_placed.csv, build_tetra_trajectories.csv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]
2026-09-30 Twin: scan a 3D object — `fieldc scan3d`, matched-field imaging in the exact glass chamber
    An object in the chamber (a cloud of small rigid scatterers) changes every
    gate-to-gate transfer; by reciprocity a scatterer at x couples gates i and j
    through p_i p_j (monopole) and grad p_i . grad p_j (dipole). Born for a cloud,
    the coupled solve for a few beads; measurement noise added (--snr, 40 dB).
    The image is the normalised matched field at every grid point, correlating
    the 36 transfers over the band (--nf, 90 frequencies 30-100 kHz; --fmax)
    with a point scatterer's predicted response, from the same exact fields.
    Objects: --object tetra (30 mm wireframe, 118 points), R (an extruded
    letter), b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
2026-09-30 Twin: the first scans — receipts at e51c922, figures
    - tetra (30 mm wireframe, 118 points): outline and inner edges back in x-y,
    blurred ~2-3 mm; 100 % of the object within 2 mm of a bright voxel.
    - R (extruded letter, 40 mm, 249 points): the letter reads in its own plane
    (stroke, bowl, leg; the top bar fainter), the 6 mm extrusion in x-y; 99 %
    recall, 33 % of the bright voxels on the letter.
    - bead-tetra (the twin's own 4-bead build, 0.4 mm across): one blob — below
    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
    [scan3d_R_grid.csv, scan3d_R_mip.csv, scan3d_R_object.csv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]
2026-09-30 Twin: the single-shot acoustic mold — and why it needs gravity as the sieve
    `fieldc mold`: release a cloud of Ø40 µm powder through the probe volume
    and let it drift, overdamped, in one compiled multi-tone field.
    - `compileMold` (wells objective): a well at every target, rivals
    suppressed. It forms 13/16 wells of a 16-site ring, but captures only
    ~22% of a uniform cloud: capture is ~90% from within 2 mm of the ring,
    37% from 3–4 mm, ~0 beyond 6 mm. A still field reaches about λ/4 of its
    lowest tone; the rest of the powder settles in layers a wavelength away.
    Gravity is not the limiter (no-gravity and 16× drive runs: same).
    - `compileFunnel` (asks U to fall toward the neare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
2026-10-01 Fix: cavity fields on the chamber axis were zero on the GPU, inexact on the CPU
    Probe lattices are centred on their target with an odd point count, so a
    target on the axis (the mid-plane centre, 100 mm above the lower face, the
    mold's tetrahedron apex) put a lattice column exactly on x = y = 0. There
    the Metal cavity kernel returned exact zeros for every tone and component
    (φ = atan2(0, 0) under fast math), and the CPU reference, while right for p,
    took J_m(μr)/r — the m = ±1 azimuthal gradient — from a spline extrapolated
    below the table's first step. Found when the tetrahedron mold's apex site
    showed exactly zero lift and the sieve compile froze (its soft-min
    temperature hit the 1e-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
2026-10-01 Twin: receipts re-run at 77df809 after the axis fix; README corrected; figures
    Every glass-chamber receipt with on-axis content, re-run at 77df809
    (+dirty only because fly/build rewrite their own tracked CSVs):
    - forcetrap --glass: 5-tone chord 0.42 → 0.34 (mid-plane), 0.36 → 0.33
    (100 mm); 1 tone 0.88 → 1.19, 0.50 → 0.57. Unique with 5 tones, as before.
    - tonesweep (mid-plane): 3/5/10/20/30 tones 0.41/0.66/0.33/0.14/0.13
    (was 0.44/0.70/0.24/0.16/0.16); GS-PAT-only chords 4.35/0.65/0.83/0.51/0.45
    at 5/10/20/40/80 tones.
    - wallsweep: a liner is still not the lever (bare 0.34, liners 0.38–0.57,
    ρc-matched 0.34).
    - levitate: glass 10 tones PLA/Al/steel 4.45/6.57/11.19 m/s (<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
    [build_placed.csv, build_tetra_placed.csv, build_tetra_trajectories.csv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]
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2026-10-02 Twin round 12: receipts, figures, README — open air, the replicator loop closes
    Receipts: the channel sweep at 9e5b63d; the molds, robustness turns, gated
    scans and replicate loops at 9af9c1f (earlier 55f9e6b/9e5b63d molds and the
    ungated scans kept as history).
    - S1: tones buy confinement along the axis (1 tone: trap ratio ~0.7 at any
    N; 9 tones over 30–70 kHz: 0.08–0.11, the ring sieve 100 % on the ring);
    channels buy power and evenness (3 → 768 per plate: ~100–170× less acoustic
    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
    [arraysweep.csv, mold_plates192_ring-rot11.25_targets.csv, mold_plates192_ring-rot5_targets.csv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]
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
